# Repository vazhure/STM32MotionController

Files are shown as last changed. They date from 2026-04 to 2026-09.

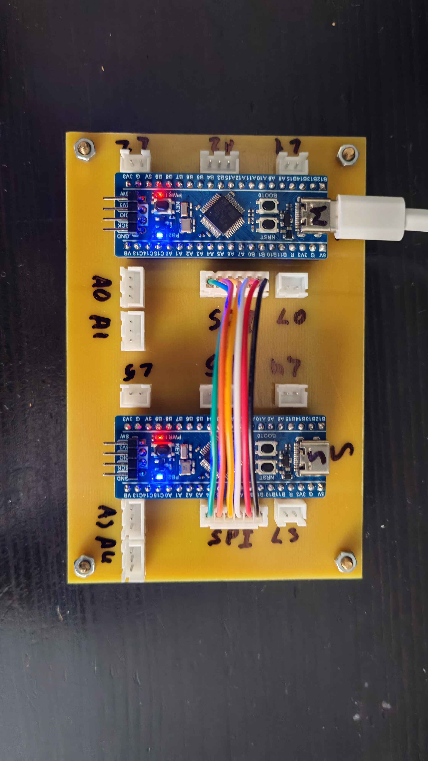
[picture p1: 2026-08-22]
STM32_F103_6DOF/photo/IMG_20260822_163101.jpg

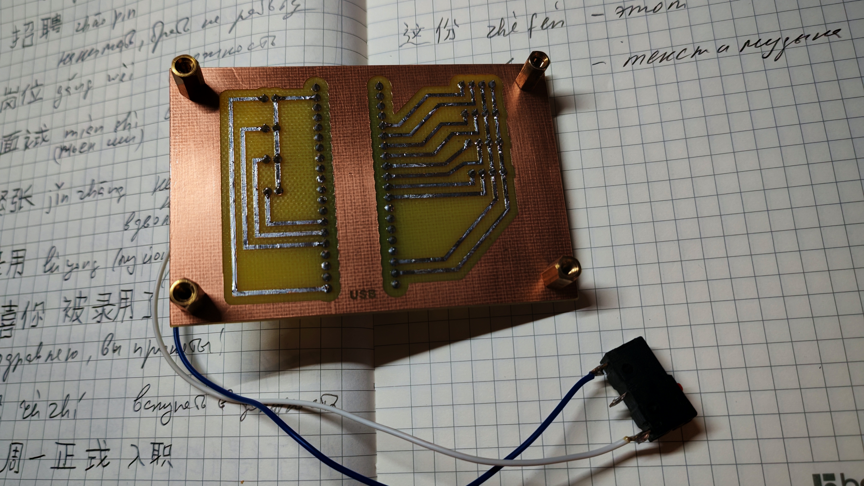
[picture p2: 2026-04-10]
STM32_F103_3DOF/img/IMG_20260410_142503.jpg

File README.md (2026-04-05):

# STM32 Motion Controller
SimHub compatible STM32 (STM32F103C8T6) based Motion Controller for Sim Racing / flight Simulators
2026-03-19 14-16-23 SettingsForm



IMG_20260319_162154_edit_288829376968099

Single STM32F103C8T6 board realization:
scheme

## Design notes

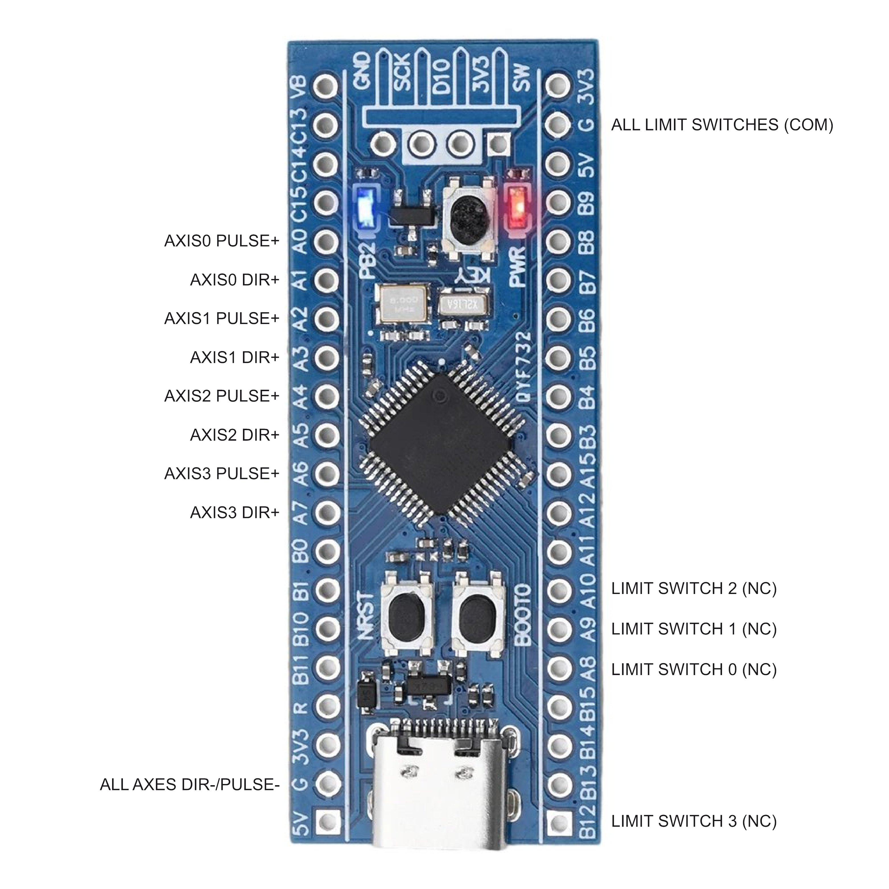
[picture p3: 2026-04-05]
STM32_F103_3DOF/img/scheme.png

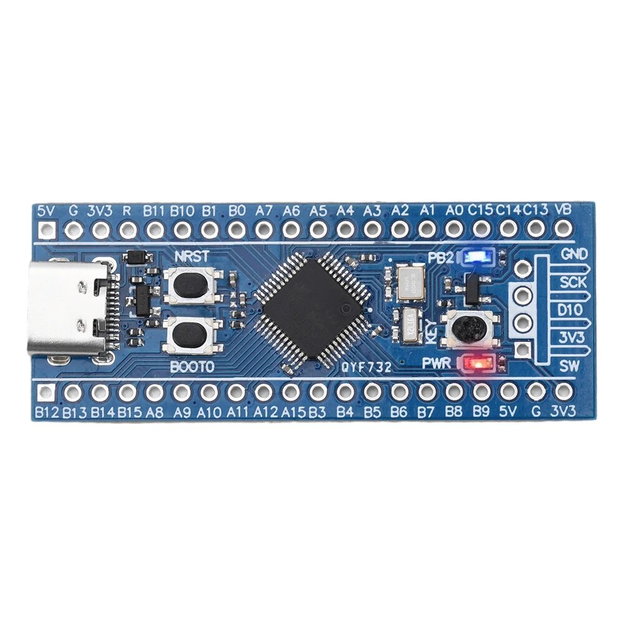
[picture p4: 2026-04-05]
STM32_F103_3DOF/img/STM32F103C8T6_TYPE_C.jpg

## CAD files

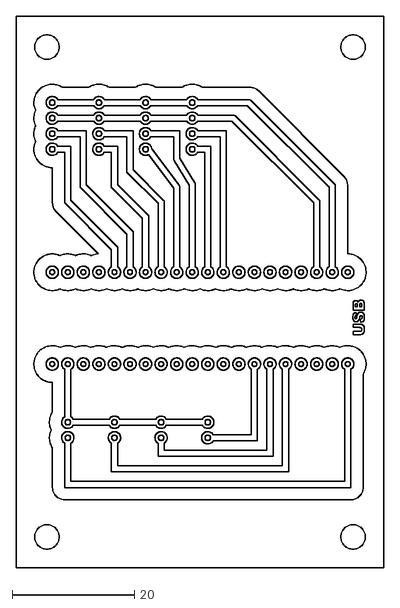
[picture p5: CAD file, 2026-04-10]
STM32_F103_3DOF/Drawings/PCB Single STM32F103_v.1.0.dxf
60.0 x 90.0

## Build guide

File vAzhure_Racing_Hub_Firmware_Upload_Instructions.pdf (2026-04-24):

vAzhure Racing Hub — Firmware Upload Instructions

## vAzhure Racing Hub

## Firmware Upload Instructions

This guide walks you through the complete process of flashing firmware onto STM32 microcontrollers used in the vAzhure Racing Hub motion controller system. You will program one Master board and up to four Slave boards, then verify that everything works with the vAzhure Racing Hub software.

Before you begin, make sure you have the following items ready:

- An ST-Link V2 (or compatible) programmer/debugger dongle
- One STM32F103C8 (or compatible) board designated as the Master
- Up to four STM32F103C8 boards designated as Slaves (Front-Left, Rear-Left, Rear-Right, Front-Right)
- USB cables to connect the ST-Link to your PC
- Jumper wires for connecting the ST-Link to each STM32 board
- The assembled PCB where the programmed boards will be installed

Warning: Always double-check the wiring connections before applying power. Connecting VCC or signal pins incorrectly may damage your STM32 board or the ST-Link programmer.

## 1. Install Required Software

You need two pieces of software installed on your computer before you can flash the firmware onto the STM32 boards. The Arduino IDE is used to compile and upload the firmware source code, while the ST-Link Utility provides the low-level USB driver that the Arduino IDE relies on for
communication with the ST-Link programmer.
Step 1.1: Download and install the Arduino IDE

Go to the official Arduino IDE releases page and download the latest version for your operating system: https://github.com/arduino/arduino-ide/releases

Run the installer and follow the on-screen prompts. Once the installation is complete, launch the Arduino IDE to verify that it opens correctly.

Step 1.2: Download and install the ST-Link USB driver

Download the ST-Link Utility from STMicroelectronics: https://www.st.com/en/development-tools/stsw-link004.html (https://www.st.com/en/development-tools/stsw-link004.html)

Install the software. This step is necessary even if you only use the Arduino IDE for uploading, because the ST-Link USB driver included in this package is required for the Arduino IDE to communicate with your ST-Link dongle.

## 2. Configure the Arduino IDE for STM32

By default, the Arduino IDE does not include support for STM32 microcontrollers. You need to add a third-party board index URL so that the IDE can download the necessary STM32 core files and board definitions.

Step 2.1: Add STM32 board manager URLs

Open the Arduino IDE and go to File > Preferences (on Windows/Linux) or Arduino IDE > Preferences (on macOS). In the Preferences window, find the field labeled "Additional boards manager URLs".

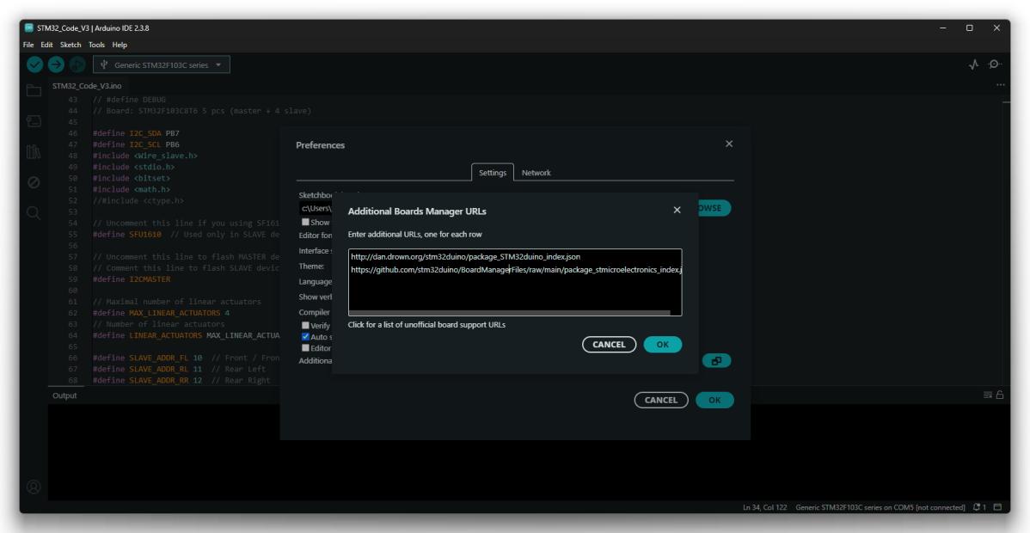
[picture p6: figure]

Append the following two URLs to that field. If there is already a URL present, separate them with a comma or place each URL on a new line:

http://dan.drown.org/stm32duino/package_STM32duino_index.json

https://github.com/stm32duino/BoardManagerFiles/raw/main/package_stmicroelectronics_index.json
Click OK to save the preferences.

Step 2.2: Install the STM32 board package

Go to Tools > Board > Boards Manager. In the search box at the top, type "STM32" and look for an entry named "STM32F1xx/GD32F1xx boards" in the list of results. Click the Install button next to it and wait for the download and installation to complete. This may take a few minutes depending on your internet speed.

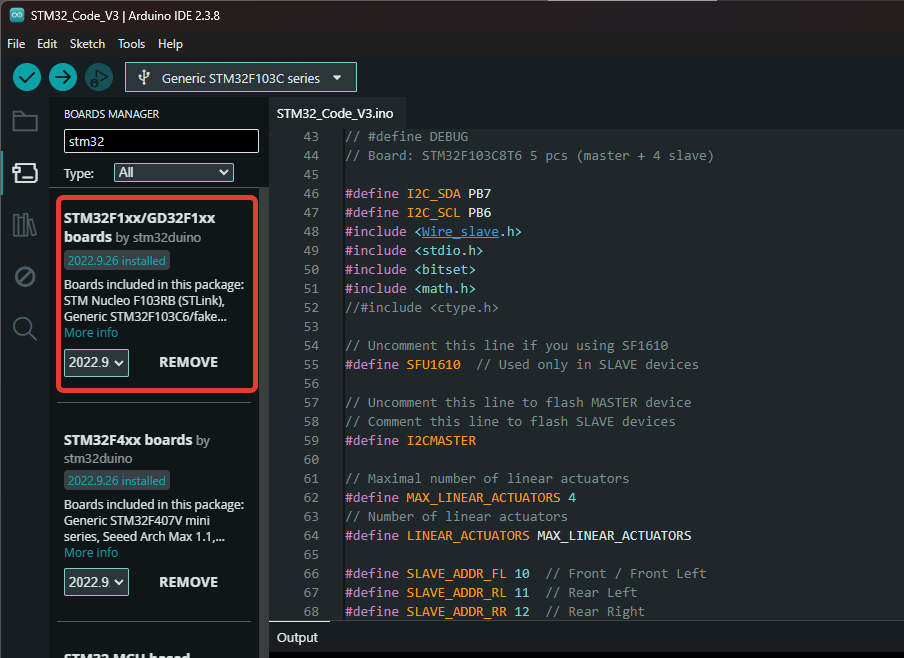
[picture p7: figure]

Step 2.3: Set the board configuration in the Tools menu

Once the STM32 board package is installed, open the Tools menu and configure the following settings exactly as shown below. These settings must match for every firmware build in this guide:

Setting | Value
Board | "Fake STM32F103C8" or "Generic STM32F103C series"
CPU Speed (MHz) | 72 MHz (Normal)
Optimize | Fast (-O1)
Upload Method | STLink

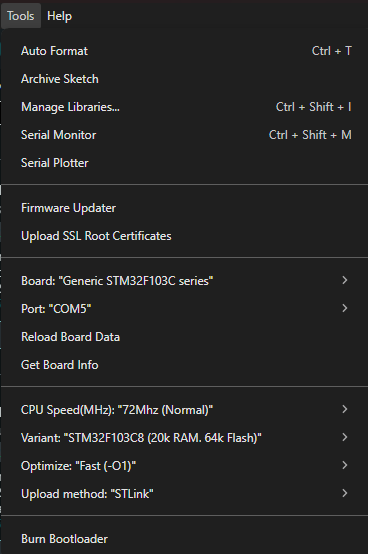
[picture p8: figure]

## 3. Wire the ST-Link to the STM32 Board

Before uploading any firmware, you need to physically connect your ST-Link programmer to the target STM32 board using jumper wires. The ST-Link communicates with the STM32 over a two-wire debug interface called SWD (Serial Wire Debug). In addition to the two data lines, you must also connect power and ground.

Use four jumper wires to make the following connections between your ST-Link dongle and the STM32 board:

ST-LINK Pin | Signal | STM32 Pin
SWCLK | → | SCK
SWDIO | → | DIO
3.3V | → | 3.3V
GND | → | GND

The following photos show how the wiring should look in practice:

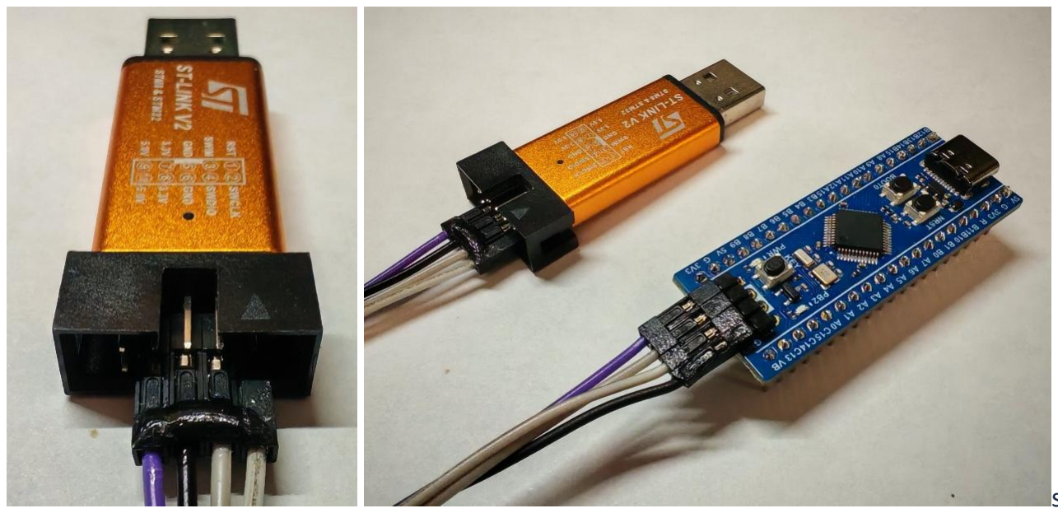
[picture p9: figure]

s

Note: Make sure the ST-Link is not connected to USB power while you are wiring the connections. Connect the USB cable only after all four wires are securely in place.

## 4. Upload the Master Firmware

The Master board is the central controller that communicates with all Slave boards over the I2C bus. It must be programmed first, because the Slave boards depend on the Master for coordination. The firmware source code is hosted on GitHub in a single sketch file.

Step 4.1: Download and open the firmware sketch

Open the following link in your browser and download the sketch file: STM32_Code_V3.ino (https://github.com/vazhure/STM32MotionController/blob/main/STM32_Code_V3/STM32_Code_V3.ino)

Open the downloaded .ino file in the Arduino IDE. The sketch will appear in the editor window.

Step 4.2: Enable the Master configuration

Near the top of the sketch file, locate the line that reads:

// #define I2CMASTER
Remove the two forward slashes at the beginning of the line so that it becomes:

#define I2CMASTER

This activates the Master mode in the firmware.

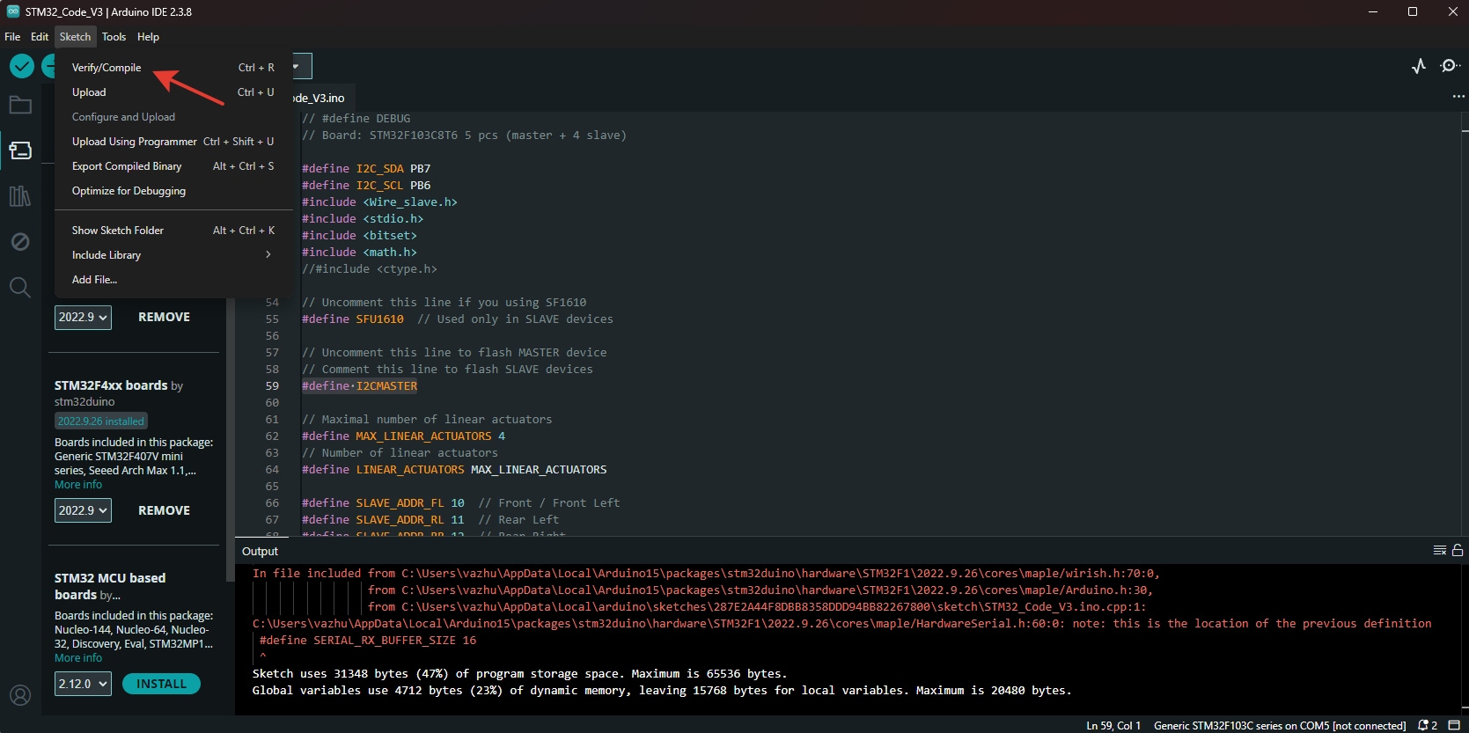
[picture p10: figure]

Step 4.3: Compile the Master firmware

Click the Verify button (the checkmark icon) in the Arduino IDE toolbar, or press Ctrl+R. Wait for the compilation to finish. If everything is configured correctly, you will see a success message in the Output panel that looks like this:

Sketch uses 31348 bytes (47%) of program storage space. Maximum is 65536 bytes.

Global variables use 4712 bytes (23%) of dynamic memory, leaving 15768 bytes for local variables. Maximum is 20480 bytes.

Note: If the compilation fails with errors, double-check that the correct board (Generic STM32F103C series) is selected in the Tools menu and that the STM32 board package was installed successfully in Step 2.2.

Step 4.4: Upload the Master firmware to the board

Connect the ST-Link dongle to your PC using a USB cable. The ST-Link driver you installed in Step 1.2 should be recognized automatically by the operating system. Then, click the Upload button (the right-arrow icon) in the Arduino IDE toolbar, or press Ctrl+U.

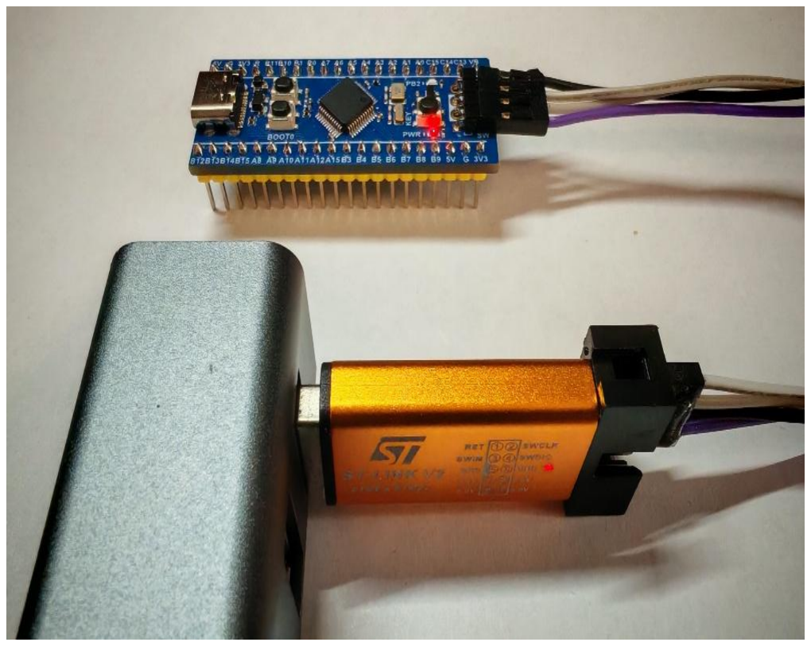
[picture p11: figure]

The Arduino IDE will compile the sketch again (if any changes were made) and then flash it onto the STM32 board through the ST-Link. Wait for the upload process to complete. A successful upload will display a message in the Output panel confirming that the firmware was written to the flash memory.

Once the upload finishes successfully, disconnect the ST-Link from the STM32 board. The Master board is now programmed and ready.

## 5. Upload the Slave Firmware

Each Slave board needs its own copy of the firmware compiled with a unique I2C address. The address is determined by which #define line is uncommented in the sketch. You will repeat the compile-and-upload cycle for each Slave board, changing only the address line each time.

Step 5.1: Switch from Master to Slave mode

In the Arduino IDE, go back to the top of the sketch file and comment out the I2CMASTER line by adding two forward slashes at the beginning:

// #define I2CMASTER
This disables Master mode and prepares the sketch for Slave mode configuration.
Step 5.2: Program the Front-Left Slave (FL)

Uncomment the line for the Front-Left slave address by removing the forward slashes:

#define SLAVE_ADDR SLAVE_ADDR_FL

Make sure all other SLAVE_ADDR lines remain commented out. Only one address line should be active at a time.

Connect the ST-Link to the Front-Left STM32 board using the same wiring diagram from Section 3. Click Verify to compile the sketch. You should see a success message similar to:

Sketch uses 34500 bytes (52%) of program storage space. Maximum is 65536 bytes.

Global variables use 4672 bytes (22%) of dynamic memory, leaving 15808 bytes for local variables. Maximum is 20480 bytes.

Click Upload to flash the firmware onto the Front-Left board. Wait for the upload to complete successfully.

Step 5.3: Program the remaining Slave boards

Repeat the process from Step 5.2 for each of the remaining Slave boards. For each board, comment out the previous SLAVE_ADDR line and uncomment the one corresponding to the current board. The complete list of Slave addresses is shown in the table below:

Slave Device | Macro to Uncomment
Front-Left (FL) | #define SLAVE_ADDR SLAVE_ADDR_FL
Rear-Left (RL) | #define SLAVE_ADDR SLAVE_ADDR_RL
Rear-Right (RR) | #define SLAVE_ADDR SLAVE_ADDR_RR
Front-Right (FR) | #define SLAVE_ADDR SLAVE_ADDR_FR

For example, to program the Rear-Left board, change the active line to:

#define SLAVE_ADDR SLAVE_ADDR_RL

Follow the same verify-and-upload cycle for each Slave: Rear-Left (RL), Rear-Right (RR), and Front-Right (FR). Connect the ST-Link to each board one at a time and upload the corresponding firmware.

Note: It is easy to forget to change the address line between uploads. Always verify that
only the correct SLAVE_ADDR line is uncommented before clicking Upload. Uploading the wrong address to a board will cause I2C communication conflicts later.

## 6. Install the Programmed Boards on the PCB

Once all boards have been successfully programmed, carefully install them onto the motion controller PCB. Pay close attention to the physical orientation and the slot assignments for each board. The Master board must be placed in its designated position, and each Slave board must occupy the correct slot matching the address that was programmed into it.

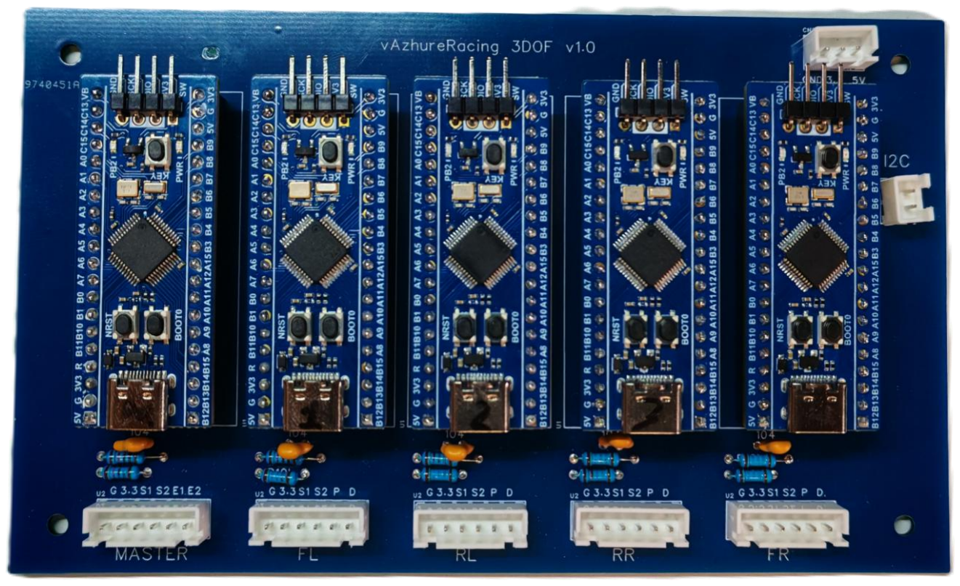
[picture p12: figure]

Verify that the boards are seated properly in their sockets and that no pins are bent or misaligned. A loose connection can cause intermittent failures that are difficult to diagnose later.

## 7. Install and Run the vAzhure Racing Hub Software

With the hardware fully assembled, the final step is to install the vAzhure Racing Hub application on your PC. This software communicates with the Master STM32 board over USB and provides the user interface for configuring and controlling the motion platform.

Step 7.1: Download and install the software

Go to the releases page on GitHub and download the latest version of the vAzhure Racing Hub: https://github.com/vazhure/vAzhureRacingHub/releases

Extract the archive and run the installer (or launch the executable directly if it is a portable version). Follow the installation prompts to complete the setup.

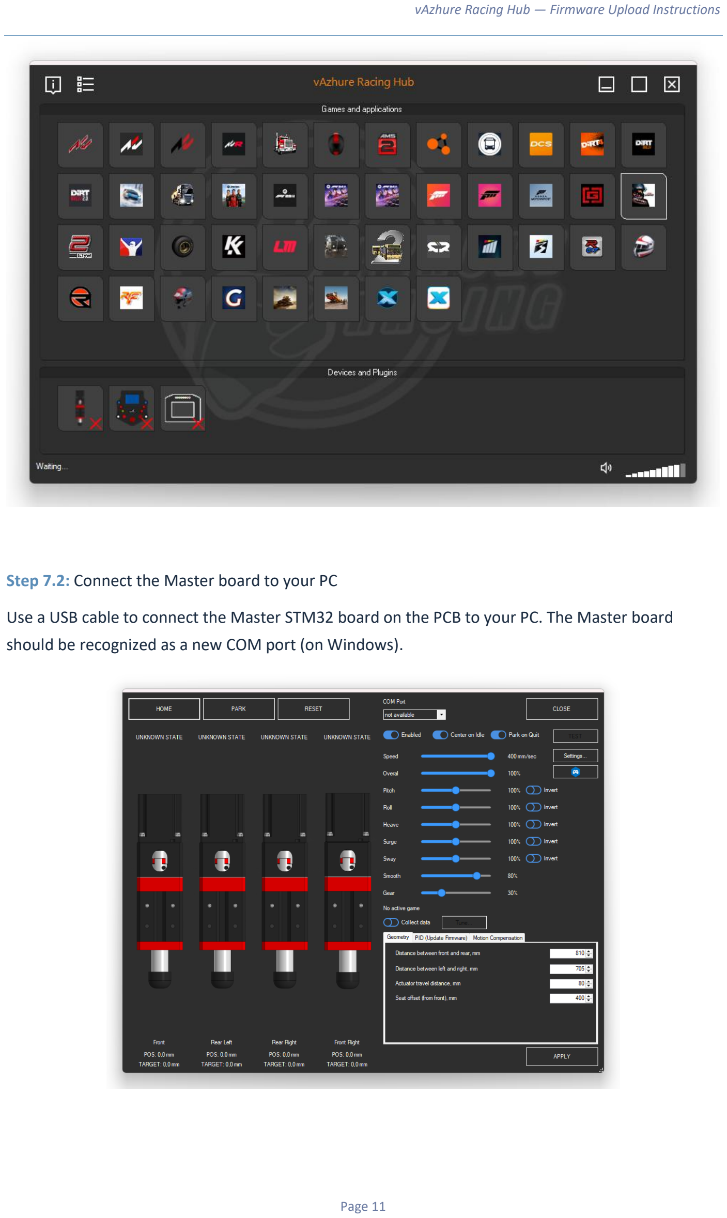
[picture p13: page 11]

Step 7.2: Connect the Master board to your PC

Use a USB cable to connect the Master STM32 board on the PCB to your PC. The Master board should be recognized as a new COM port (on Windows).

Step 7.3: Detect the device in the software

Launch the vAzhure Racing Hub application. Click the device detection icon in the toolbar to scan for connected hardware.

When the software detects the Master board, a dialog will appear asking whether you want to register the new device. Click "Yes" to confirm.

Step 7.4: Verify the setup

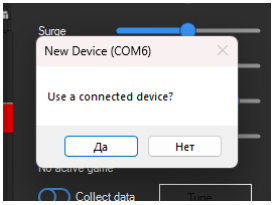
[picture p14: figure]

If the PCB is assembled correctly and all firmware was flashed properly, the software should display the full system status with all Slave boards reporting in. You should see indicators for each axis (Front-Left, Front-Right, Rear-Left, Rear-Right) showing that they are online and responding to commands from the Master.

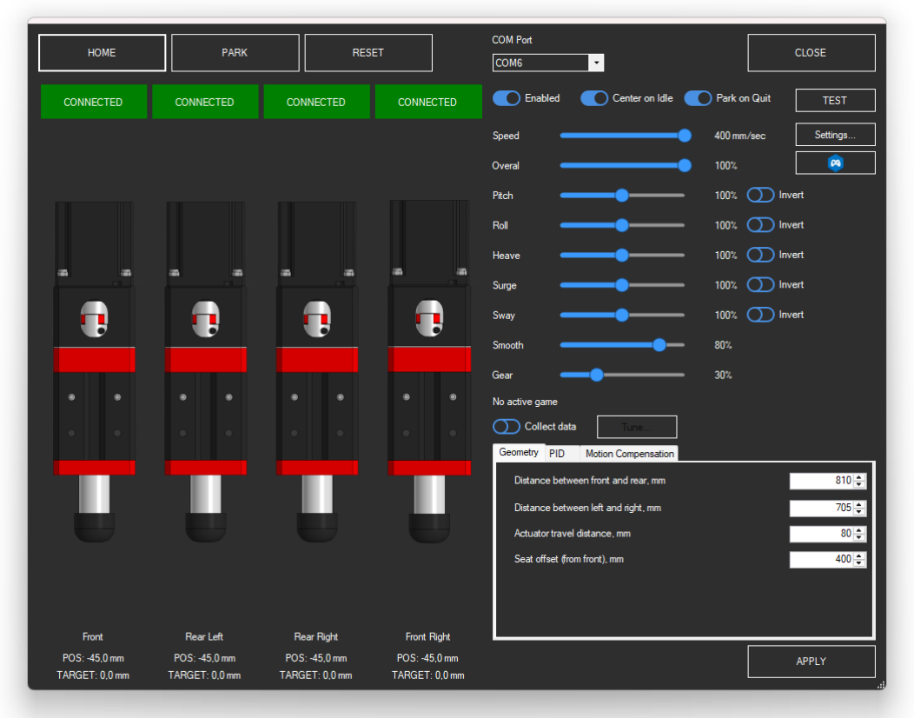
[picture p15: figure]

If any boards are not showing up, go back and verify the following:

- The correct firmware was uploaded to each board (check the SLAVE_ADDR lines)
- All boards are properly seated in their PCB sockets
- The USB cable and connection are working (try a different cable or port)
- The ST-Link USB driver is installed (required for COM port detection)

Congratulations! Your vAzhure Racing Hub motion controller is now fully set up and ready to use.

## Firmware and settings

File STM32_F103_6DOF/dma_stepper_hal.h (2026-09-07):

// 3DOF by Andrey Zhuravlev
// v.azhure@gmail.com
// Discord: https://discord.gg/ynHCkrsmMA
// ============================================================================
// CHANGELOG:
// 2026-09-07: Acceleration fix. CMD_ENABLE fix (preserve PARKED state)
// 2026-08-19: Added COMMAND enum to make it visible in both .cpp and .ino files.
// 2026-08-18: Merged 6-axis SPI Master/Slave support with advanced limit switch config.
// ============================================================================
#ifndef DMA_STEPPER_HAL_H
#define DMA_STEPPER_HAL_H
#include <Arduino.h>

// =============================================================================
// 🛠️ USER CONFIGURATION (Modify only these values)
// =============================================================================
#define MM_PER_REV 8.0f
#define STEPS_PER_REV 1600
#define MAX_REVOLUTIONS 20.0f

#define HOME_DIRECTION -1
#define END_CLEARANCE_MM 3.0f

#define LIMIT_TYPE_NC 0
#define LIMIT_TYPE_NO 1
#define LIMIT_PULL_UP 0
#define LIMIT_PULL_DOWN 1
#define LIMIT_PULL_AUTO 2

#ifndef LIMIT_SWITCH_TYPE
#define LIMIT_SWITCH_TYPE LIMIT_TYPE_NO
#endif
#ifndef LIMIT_PULL_MODE
#define LIMIT_PULL_MODE LIMIT_PULL_AUTO
#endif

#if (LIMIT_PULL_MODE == LIMIT_PULL_AUTO)
#if (LIMIT_SWITCH_TYPE == LIMIT_TYPE_NC)
#define _RESOLVED_PULL LIMIT_PULL_UP
#else
#define _RESOLVED_PULL LIMIT_PULL_DOWN
#endif
#else
#define _RESOLVED_PULL LIMIT_PULL_MODE
#endif

#if (LIMIT_SWITCH_TYPE == LIMIT_TYPE_NC)
#if (_RESOLVED_PULL == LIMIT_PULL_UP)
#define LIMIT_ACTIVE_HIGH 1
#else
#define LIMIT_ACTIVE_HIGH 0
#endif
#else
#if (_RESOLVED_PULL == LIMIT_PULL_UP)
#define LIMIT_ACTIVE_HIGH 0
#else
#define LIMIT_ACTIVE_HIGH 1
#endif
#endif

#define END_CLEARANCE_STEPS ((int32_t)(END_CLEARANCE_MM * (float)STEPS_PER_REV / (float)MM_PER_REV))

// =============================================================================
// ENABLE SWITCH  CONFIGURATION
// =============================================================================
#define ENABLE_PIN PB11 // PB12, PB6, PB7, PB8, PB9  // NC button: LOW = running, HIGH = paused

// =============================================================================
// MULTI-CONTROLLER CONFIGURATION
// =============================================================================
#define AXES_PER_BOARD 3
#define AXES_TOTAL 6

#define CONTROLLER_MODE_MASTER 0
#define CONTROLLER_MODE_SLAVE 1

#ifndef CONTROLLER_MODE
#define CONTROLLER_MODE CONTROLLER_MODE_SLAVE
#endif

#if (CONTROLLER_MODE == CONTROLLER_MODE_SLAVE)
#define LOGICAL_AXIS_OFFSET AXES_PER_BOARD
#else
#define LOGICAL_AXIS_OFFSET 0
#endif

#define SPI_SCK_PIN PA5
#define SPI_MISO_PIN PA6
#define SPI_MOSI_PIN PA7
#define SPI_NSS_PIN PA4
#define SYNC_PIN PB0
#define ALARM_PIN PB1

#define SPI_HEADER_MAGIC 0xAA

// 2026-08-19 FIX: Double underscore for packed attribute
typedef struct __attribute__((packed)) {
  uint8_t header;
  uint8_t frameId;
  uint8_t command;
  uint8_t flags;
  int32_t cmdData[3];
  int32_t positions[3];
  int32_t targets[3];
  uint8_t modes[3];
  uint8_t slaveStatus;
} SPI_FRAME;

#define SPI_FLAG_SYNC 0x01
#define SPI_FLAG_ALARM 0x02

// =============================================================================
// PROTOCOL COMMANDS (Moved here so .cpp and .ino can both see them)
// =============================================================================
enum COMMAND : uint8_t {
  CMD_HOME = 0,
  CMD_MOVE = 1,
  CMD_SET_SPEED = 2,
  CMD_DISABLE = 3,
  CMD_ENABLE = 4,
  CMD_GET_STATE = 5,
  CMD_CLEAR_ALARM = 6,
  CMD_PARK = 7,
  SET_ALARM = 8,
  CMD_SET_LOW_SPEED = 9,
  CMD_SET_ACCEL = 10,
  CMD_MOVE_SH = 11,
  CMD_SET_PID_KP = 0x0C,
  CMD_SET_PID_KI = 0x0D,
  CMD_SET_PID_KD = 0x0E,
  CMD_SET_PID_KS = 0x0F,
  CMD_SET_PID_ENABLE = 0x10,
  CMD_SET_PID_BLEND = 0x11,
  CMD_GET_PID_STATE = 0x12,
  CMD_STORE_PID = 0x13,
  CMD_RESTORE_PID = 0x14,
};

// =============================================================================
// UNIT CONVERSION MACROS
// =============================================================================
#define MMPERSECTOFREQHZ(mmpers) ((uint32_t)((float)(mmpers) * (float)STEPS_PER_REV / (float)MM_PER_REV))
#define FREQHZTOMMPERSEC(freqhz) ((float)(freqhz) * (float)MM_PER_REV / (float)STEPS_PER_REV)
#define MMPERSECTOFREQHZ_SAFE(mmpers) constrain(MMPERSECTOFREQHZ(mmpers), MIN_FREQUENCY_HZ, MAX_FREQUENCY_HZ)

#define MAX_FREQUENCY_HZ 200000
#define SAFE_FREQUENCY_HZ 100000
#define DEFAULT_FREQUENCY_HZ SAFE_FREQUENCY_HZ
#define MIN_FREQUENCY_HZ 50

#define HOMING_FREQUENCY_HZ MMPERSECTOFREQHZ_SAFE(15)
#define PARKING_FREQUENCY_HZ MMPERSECTOFREQHZ_SAFE(15)
#define HOMING_RETRACT_DISTANCE_MM 3.0f
#define HOMING_RETRACT_DURATION_MS ((uint32_t)((HOMING_RETRACT_DISTANCE_MM * (float)STEPS_PER_REV * 1000.0f) / ((float)HOMING_FREQUENCY_HZ * MM_PER_REV)))
#define HOMING_SEEK_TIMEOUT_MS 30000
#define HOMING_CENTER_TIMEOUT_MS 30000
#define MAX_ACCEL 80000
#define HOMING_TRAVEL_LIMIT_MULT 1.5f
#define HOMING_OVERFLOW_LIMIT_MULT 1.4f
#define POSITION_TOLERANCE 50

#define POSITION_DEADZONE 4 //2
#define ACCEL_RAMP_DISTANCE 800 //50

// S-curve softening: limit how fast frequency can change per call
// This prevents "frequency shock" when target changes abruptly
#define MAX_FREQ_DELTA_PER_CALL 2000 

#define DIRECTION_CHANGE_DELAY_US 10
#define HOMING_CENTER_TOLERANCE 100
#define HOMING_RETRACT_SETTLE_MS 50

// =============================================================================
// SYSTEM CONSTANTS
// =============================================================================
#define MM_PER_STEP (MM_PER_REV / STEPS_PER_REV)
#define MAX_SPEED_MM_SEC (int)(MAX_FREQUENCY_HZ * MM_PER_STEP)
#define SAFE_SPEED_MM_SEC (int)(SAFE_FREQUENCY_HZ * MM_PER_STEP)
#define DEFAULT_SPEED_MM_SEC (int)(DEFAULT_FREQUENCY_HZ * MM_PER_STEP)
#define NUM_AXES AXES_PER_BOARD
#define PENDING_TARGET_NONE INT32_MIN

// =============================================================================
// DATA STRUCTURES
// =============================================================================
typedef struct {
  uint8_t stepPin;
  uint8_t dirPin;
  uint8_t limitPin;
} AxisConfig;

typedef struct {
  volatile int32_t currentPosition;
  volatile int32_t targetPosition;
  volatile int32_t minPos;
  volatile int32_t maxPos;
  volatile uint32_t frequency;
  volatile bool direction;
  volatile bool stepping;
  volatile bool homed;
  volatile uint8_t mode;
  uint32_t maxFreqHz;
  uint32_t maxSpeedMM;
  float limitedFreq;
  uint32_t accelLastTime;
  uint32_t pidLastTime;
  uint32_t maxAccel;
  float Kp, Ki, Kd, Ks;
  float integral;
  float prevError;
  float derivativeFilter;
  float pidMinFreq;
  float pidMaxFreq;
  bool pidEnabled;
  float pidBlend;
  int32_t pendingTarget;
} AxisState;

enum AxisMode {
  MODE_UNKNOWN = 0,
  MODE_CONNECTED = 1,
  MODE_DISABLED = 2,
  MODE_HOMING = 3,
  MODE_PARKING = 4,
  MODE_READY = 5,
  MODE_ALARM = 6,
  MODE_PARKED = 7,
  MODE_UNPARKING = 8
};

enum HomingSubState {
  H_IDLE = 0,
  H_SEEKING,
  H_RETRACT,
  H_RETRACT_SETTLE,
  H_MOVING_CENTER,
  H_DONE
};

// =============================================================================
// API FUNCTIONS
// =============================================================================
void DMAStepper_Init(void);
void DMAStepper_InitAxis(uint8_t axisIdx, uint8_t stepPin, uint8_t dirPin, uint8_t limitPin);
void DMAStepper_SetFrequency(uint8_t axisIdx, uint32_t freqHz);
void DMAStepper_StartAxis(uint8_t axisIdx, bool forward);
void DMAStepper_StopAxis(uint8_t axisIdx);
void DMAStepper_StopAll(void);
void DMAStepper_SetTarget(uint8_t axisIdx, int32_t target);
int32_t DMAStepper_GetPosition(uint8_t axisIdx);
void DMAStepper_SetPosition(uint8_t axisIdx, int32_t pos);
AxisState* DMAStepper_GetAxis(uint8_t axisIdx);
void DMAStepper_SetMaxSpeed(uint8_t axisIdx, uint32_t speedMM);
void DMAStepper_SetPID(uint8_t axisIdx, float Kp, float Ki, float Kd, float Ks);
void DMAStepper_SetPIDEnable(uint8_t axisIdx, bool enable);
void DMAStepper_SetPIDBlend(uint8_t axisIdx, float blend);
bool DMAStepper_CheckLimit(uint8_t axisIdx);
void DMAStepper_ClearAlarm(void);
void DMAStepper_Process(void);
void DMAStepper_StartHoming(uint8_t axisIdx);

void SPI_Controller_Init(void);
void SPI_Controller_Process(void);
void SPI_PingSlave(void); 
bool SPI_Controller_SendCommand(uint8_t cmd, int32_t* data, bool sync);
bool SPI_Controller_IsSlaveReady(void);
void SPI_Controller_TriggerAlarm(void);
SPI_FRAME* SPI_Controller_GetLastFrame(void);

#endif

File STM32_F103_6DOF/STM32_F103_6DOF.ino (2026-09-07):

/*
🛠️ COMPILATION & SETUP INSTRUCTIONS
Board: "Generic STM32F1 series" → "Blue Pill F103C8"
Upload method: "STLink", CPU Speed: "72 MHz (Normal)"

6-AXIS SYSTEM WIRING (identical on both boards):
AXIS0: PA0 (STEP), PA1 (DIR), PB10 (LIMIT)
AXIS1: PA2 (STEP), PA3 (DIR), PA8  (LIMIT)
AXIS2: PB3 (STEP), PB4 (DIR), PB5  (LIMIT)

SPI interconnect (Master ↔ Slave):
PA5 (SCK), PA6 (MISO), PA7 (MOSI), PA4 (NSS)
PB0 (SYNC), PB1 (ALARM), GND (common ground required!)

MASTER board: connect USB to PC/SimHub
SLAVE board:  powered separately, no USB needed

IMPORTANT: 
To compile for Master, ensure dma_stepper_hal.h has: #define CONTROLLER_MODE CONTROLLER_MODE_MASTER
To compile for Slave, ensure dma_stepper_hal.h has:  #define CONTROLLER_MODE CONTROLLER_MODE_SLAVE
*/

// 2026-09-07: Acceleration fix. CMD_ENABLE fix (preserve PARKED state)
// 2026-08-23 CRITICAL FIX: Disable JTAG to free PB3, PB4, PA15 for GPIO use.
// 2026-08-19: Moved COMMAND enum to dma_stepper_hal.h to fix compilation scope errors.
// 3DOF by Andrey Zhuravlev
// v.azhure@gmail.com
// Discord: https://discord.gg/ynHCkrsmMA

#include "dma_stepper_hal.h"
#include <EEPROM.h>
#include <string.h>

#define SERIAL_BAUD_RATE 115200
#define PID_KP_SCALE 10.0f
#define PID_KI_SCALE 10.0f
#define PID_KD_SCALE 100.0f
#define PID_KS_SCALE 100.0f
#define SH_DATA_MAX_VALUE 65535

#define AXIS0_STEP PA0
#define AXIS0_DIR PA1
#define AXIS0_LIMIT PB10
#define AXIS1_STEP PA2
#define AXIS1_DIR PA3
#define AXIS1_LIMIT PA8
#define AXIS2_STEP PB3
#define AXIS2_DIR PB4
#define AXIS2_LIMIT PB5
#define LED_PIN PB2

#define CMD_ID 0
#define STATE_SIZE 20
#define PID_STATE_SIZE 20

// enum COMMAND удален отсюда, так как теперь он объявлен в dma_stepper_hal.h

struct __attribute__((packed)) PCCMD {
  uint8_t header;
  uint8_t len;
  COMMAND cmd;
  uint8_t reserved;
  int32_t data[AXES_TOTAL];
};

struct __attribute__((packed)) PCCMD_SH {
  uint8_t header = 0;
  uint8_t len;
  COMMAND cmd;
  uint8_t reserved;
  uint16_t data[AXES_TOTAL];
  uint16_t data2[AXES_TOTAL];
};

struct __attribute__((packed)) STATE {
  uint8_t mode;
  uint8_t flags;
  uint16_t speedMMperSEC;
  int32_t currentpos;
  int32_t targetpos;
  int32_t min;
  int32_t max;
};

struct __attribute__((packed)) PID_STATE {
  uint8_t version;
  uint8_t flags;
  uint16_t blend;
  float Kp, Ki, Kd, Ks;
};

enum PID_FLAGS : uint8_t {
  PID_NONE = 0,
  PID_ENABLED = 1,
  PID_MASTER_SYNC = 1 << 1,
  PID_DIAG_ENABLED = 1 << 2
};

PCCMD pccmd;
PCCMD_SH& pccmd_sh = (PCCMD_SH&)pccmd;
const int RAW_DATA_LEN = sizeof(PCCMD);

volatile bool dataReceived = false;
uint8_t rxBuffer[RAW_DATA_LEN * 2];
int rxOffset = 0;

PID_STATE pidGlobal = {
  .version = 1, .flags = PID_FLAGS::PID_ENABLED, .blend = 100, .Kp = 15.0f, .Ki = 0.0f, .Kd = 0.02f, .Ks = 0.30f
};
const int PID_STATE_LEN = sizeof(PID_STATE);
#define PID_EEPROM_MAGIC 0x5A
#define PID_EEPROM_ADDR 0

void savePidToEEPROM() {
  EEPROM.update(PID_EEPROM_ADDR, PID_EEPROM_MAGIC);
  uint8_t* p = (uint8_t*)&pidGlobal;
  for (int i = 0; i < PID_STATE_LEN; i++) EEPROM.update(PID_EEPROM_ADDR + 1 + i, p[i]);
}

bool loadPidFromEEPROM() {
  if (EEPROM.read(PID_EEPROM_ADDR) != PID_EEPROM_MAGIC) return false;
  uint8_t* p = (uint8_t*)&pidGlobal;
  for (int i = 0; i < PID_STATE_LEN; i++) p[i] = EEPROM.read(PID_EEPROM_ADDR + 1 + i);
  return true;
}

void sendAllStates() {
  for (int logicalAxis = 0; logicalAxis < AXES_TOTAL; logicalAxis++) {
    STATE s;
    memset(&s, 0, sizeof(s));

#if (CONTROLLER_MODE == CONTROLLER_MODE_MASTER)
    if (logicalAxis < AXES_PER_BOARD) {
      AxisState* ax = DMAStepper_GetAxis(logicalAxis);
      if (!ax) continue;
      s.mode = ax->mode;
      s.flags = ax->homed ? 0x02 : 0;
      s.speedMMperSEC = (uint16_t)ax->maxSpeedMM;
      s.currentpos = ax->currentPosition;
      s.targetpos = ax->targetPosition;
      s.min = ax->minPos;
      s.max = ax->maxPos;
    } else {
      // Remote axes 3-5 (from Slave via SPI)
      int slaveIdx = logicalAxis - AXES_PER_BOARD;
      SPI_FRAME* frame = SPI_Controller_GetLastFrame();

      // 2026-08-19 CRITICAL FIX: NEVER skip axes — always send something.
      // If Slave is offline/in alarm, send explicit "no data" state with flag 0x08.
      if (!frame) {
        s.mode = 0;      // MODE_UNKNOWN
        s.flags = 0x08;  // Special flag: "no data from slave"
        s.speedMMperSEC = 0;
        s.currentpos = 0;
        s.targetpos = 0;
        s.min = 0;
        s.max = 0;
      } else {
        s.mode = frame->modes[slaveIdx];
        s.flags = (frame->slaveStatus & (1 << slaveIdx)) ? 0x02 : 0;
        if (frame->slaveStatus & 0x08) s.flags |= 0x04;  // Alarm flag
        s.speedMMperSEC = 0;
        s.currentpos = frame->positions[slaveIdx];
        s.targetpos = frame->targets[slaveIdx];
        AxisState* ax = DMAStepper_GetAxis(slaveIdx);
        s.min = ax->minPos;
        s.max = ax->maxPos;
      }
    }
#else
    if (logicalAxis < LOGICAL_AXIS_OFFSET || logicalAxis >= LOGICAL_AXIS_OFFSET + AXES_PER_BOARD) continue;
    int localIdx = logicalAxis - LOGICAL_AXIS_OFFSET;
    AxisState* ax = DMAStepper_GetAxis(localIdx);
    if (!ax) continue;
    s.mode = ax->mode;
    s.flags = ax->homed ? 0x02 : 0;
    s.speedMMperSEC = (uint16_t)ax->maxSpeedMM;
    s.currentpos = ax->currentPosition;
    s.targetpos = ax->targetPosition;
    s.min = ax->minPos;
    s.max = ax->maxPos;
#endif

    Serial.write(10 + logicalAxis);
    Serial.write(STATE_SIZE);
    Serial.write((uint8_t*)&s, STATE_SIZE);
  }
}

void sendPIDState() {
  Serial.write(255);
  Serial.write(PID_STATE_SIZE);
  Serial.write((uint8_t*)&pidGlobal, PID_STATE_SIZE);
}

void processCommand() {
  switch (pccmd.cmd) {
    case CMD_MOVE:
      {
#if (CONTROLLER_MODE == CONTROLLER_MODE_MASTER)
        for (int i = 0; i < AXES_PER_BOARD; i++) {
          AxisState* ax = DMAStepper_GetAxis(i);
          if (!ax || !ax->homed) continue;
          if (ax->mode == MODE_READY) DMAStepper_SetTarget(i, pccmd.data[i]);
          else if (ax->mode == MODE_PARKED || ax->mode == MODE_UNPARKING) {
            ax->pendingTarget = pccmd.data[i];
            if (ax->mode == MODE_PARKED) ax->mode = MODE_UNPARKING;
          }
        }
        int32_t slaveData[3] = { pccmd.data[3], pccmd.data[4], pccmd.data[5] };
        SPI_Controller_SendCommand(CMD_MOVE, slaveData, false);
#endif
        break;
      }
    case CMD_MOVE_SH:
      {
#if (CONTROLLER_MODE == CONTROLLER_MODE_MASTER)
        for (int i = 0; i < AXES_PER_BOARD; i++) {
          uint16_t val = pccmd_sh.data[i];
          val = (val >> 8) | (val << 8);
          AxisState* ax = DMAStepper_GetAxis(i);
          if (!ax || !ax->homed) continue;
          int32_t target = map(val, 0, SH_DATA_MAX_VALUE, ax->minPos, ax->maxPos);
          if (ax->mode == MODE_READY) DMAStepper_SetTarget(i, target);
          else if (ax->mode == MODE_PARKED || ax->mode == MODE_UNPARKING) {
            ax->pendingTarget = target;
            if (ax->mode == MODE_PARKED) ax->mode = MODE_UNPARKING;
          }
        }
        int32_t slaveData[AXES_PER_BOARD];
        for (int i = 0; i < AXES_PER_BOARD; i++) {
          uint16_t val = pccmd_sh.data[AXES_PER_BOARD + i];
          val = (val >> 8) | (val << 8);
          AxisState* refAx = DMAStepper_GetAxis(0);
          if (refAx) slaveData[i] = map(val, 0, SH_DATA_MAX_VALUE, refAx->minPos, refAx->maxPos);
        }
        SPI_Controller_SendCommand(CMD_MOVE, slaveData, false);
#endif
        break;
      }
    case CMD_SET_SPEED:
      {
#if (CONTROLLER_MODE == CONTROLLER_MODE_MASTER)
        for (int i = 0; i < AXES_PER_BOARD; i++) DMAStepper_SetMaxSpeed(i, (uint32_t)pccmd.data[0]);
        int32_t spdData[3] = { pccmd.data[0], 0, 0 };
        SPI_Controller_SendCommand(CMD_SET_SPEED, spdData, false);
#endif
        break;
      }
    case CMD_SET_ACCEL:
      {
#if (CONTROLLER_MODE == CONTROLLER_MODE_MASTER)
        for (int i = 0; i < AXES_PER_BOARD; i++) {
          AxisState* ax = DMAStepper_GetAxis(i);
          if (ax) ax->maxAccel = pccmd.data[0];
        }
        int32_t accData[3] = { pccmd.data[0], 0, 0 };
        SPI_Controller_SendCommand(CMD_SET_ACCEL, accData, false);
#endif
        break;
      }
    case CMD_ENABLE:
      {
#if (CONTROLLER_MODE == CONTROLLER_MODE_MASTER)
        for (int i = 0; i < AXES_PER_BOARD; i++) {
          AxisState* ax = DMAStepper_GetAxis(i);
          if (!ax) continue;

          // CRITICAL FIX: Only transition to READY from safe states.
          // Do NOT override PARKED/PARKING/UNPARKING — the unpark logic
          // must complete its smooth centering sequence first.
          // Do NOT override HOMING — let it finish.
          // Do NOT override ALARM — user must clear it explicitly.
          if (ax->mode == MODE_CONNECTED || ax->mode == MODE_DISABLED || ax->mode == MODE_UNKNOWN) {
            ax->mode = ax->homed ? MODE_READY : MODE_CONNECTED;
          }
          // PARKED stays PARKED → CMD_MOVE will trigger UNPARKING naturally
          // HOMING stays HOMING → will transition to READY when done
          // ALARM stays ALARM → user must press CLEAR_ALARM
        }
        SPI_Controller_SendCommand(CMD_ENABLE, nullptr, false);
#endif
        break;
      }
    case CMD_DISABLE:
      {
#if (CONTROLLER_MODE == CONTROLLER_MODE_MASTER)
        DMAStepper_StopAll();
        for (int i = 0; i < AXES_PER_BOARD; i++) {
          AxisState* ax = DMAStepper_GetAxis(i);
          if (ax) ax->mode = MODE_DISABLED;
        }
        SPI_Controller_SendCommand(CMD_DISABLE, nullptr, false);
#endif
        break;
      }
    case CMD_CLEAR_ALARM:
      {
#if (CONTROLLER_MODE == CONTROLLER_MODE_MASTER)
        DMAStepper_ClearAlarm();
        SPI_Controller_SendCommand(CMD_CLEAR_ALARM, nullptr, false);
#endif
        break;
      }
    case CMD_HOME:
      {
#if (CONTROLLER_MODE == CONTROLLER_MODE_MASTER)
        for (int i = 0; i < AXES_PER_BOARD; i++) {
          AxisState* ax = DMAStepper_GetAxis(i);
          if (!ax) continue;
          // 2026-08-21 FIX: Игнорируем команду, если гоминг уже идет
          if (ax->mode == MODE_HOMING) continue;
          if (ax->homed && (ax->mode == MODE_READY || ax->mode == MODE_PARKED)) continue;
          DMAStepper_StartHoming(i);
        }
        SPI_Controller_SendCommand(CMD_HOME, nullptr, false);
#endif
        break;
      }
    case CMD_PARK:
      {
#if (CONTROLLER_MODE == CONTROLLER_MODE_MASTER)
        for (int i = 0; i < AXES_PER_BOARD; i++) {
          AxisState* ax = DMAStepper_GetAxis(i);
          if (ax && ax->homed) ax->mode = MODE_PARKING;
        }
        SPI_Controller_SendCommand(CMD_PARK, nullptr, false);
#endif
        break;
      }
    case SET_ALARM:
      {
#if (CONTROLLER_MODE == CONTROLLER_MODE_MASTER)
        DMAStepper_StopAll();
        for (int i = 0; i < AXES_PER_BOARD; i++) {
          AxisState* ax = DMAStepper_GetAxis(i);
          if (ax) {
            ax->mode = MODE_ALARM;
            ax->homed = false;
          }
        }
        SPI_Controller_SendCommand(SET_ALARM, nullptr, false);
#endif
        break;
      }
    case CMD_GET_STATE:
      {
#if (CONTROLLER_MODE == CONTROLLER_MODE_MASTER)
        SPI_Controller_SendCommand(CMD_GET_STATE, nullptr, false);
#endif
        sendAllStates();
        break;
      }
    case CMD_SET_PID_KP:
      {
        pidGlobal.Kp = constrain((float)pccmd.data[0] / PID_KP_SCALE, 0.0f, 200.0f);
        for (int i = 0; i < AXES_PER_BOARD; i++) DMAStepper_SetPID(i, pidGlobal.Kp, pidGlobal.Ki, pidGlobal.Kd, pidGlobal.Ks);
        break;
      }
    case CMD_SET_PID_KI:
      {
        pidGlobal.Ki = constrain((float)pccmd.data[0] / PID_KI_SCALE, 0.0f, 50.0f);
        for (int i = 0; i < AXES_PER_BOARD; i++) DMAStepper_SetPID(i, pidGlobal.Kp, pidGlobal.Ki, pidGlobal.Kd, pidGlobal.Ks);
        break;
      }
    case CMD_SET_PID_KD:
      {
        pidGlobal.Kd = constrain((float)pccmd.data[0] / PID_KD_SCALE, 0.0f, 50.0f);
        for (int i = 0; i < AXES_PER_BOARD; i++) DMAStepper_SetPID(i, pidGlobal.Kp, pidGlobal.Ki, pidGlobal.Kd, pidGlobal.Ks);
        break;
      }
    case CMD_SET_PID_KS:
      {
        pidGlobal.Ks = constrain((float)pccmd.data[0] / PID_KS_SCALE, 0.0f, 1.0f);
        for (int i = 0; i < AXES_PER_BOARD; i++) DMAStepper_SetPID(i, pidGlobal.Kp, pidGlobal.Ki, pidGlobal.Kd, pidGlobal.Ks);
        break;
      }
    case CMD_SET_PID_ENABLE:
      {
        for (int i = 0; i < AXES_PER_BOARD; i++) DMAStepper_SetPIDEnable(i, pccmd.data[0] != 0);
        if (pccmd.data[0]) pidGlobal.flags |= PID_FLAGS::PID_ENABLED;
        else pidGlobal.flags &= ~PID_FLAGS::PID_ENABLED;
        break;
      }
    case CMD_SET_PID_BLEND:
      {
        pidGlobal.blend = constrain((uint16_t)pccmd.data[0], 0, 100);
        for (int i = 0; i < AXES_PER_BOARD; i++) DMAStepper_SetPIDBlend(i, (float)pidGlobal.blend / 100.0f);
        break;
      }
    case CMD_GET_PID_STATE:
      {
        sendPIDState();
        break;
      }
    case CMD_STORE_PID:
      {
        savePidToEEPROM();
        break;
      }
    case CMD_RESTORE_PID:
      {
        if (loadPidFromEEPROM()) {
          bool pidWasEnabled = (pidGlobal.flags & PID_FLAGS::PID_ENABLED) != 0;
          for (int i = 0; i < AXES_PER_BOARD; i++) {
            DMAStepper_SetPIDEnable(i, false);
            DMAStepper_SetPID(i, pidGlobal.Kp, pidGlobal.Ki, pidGlobal.Kd, pidGlobal.Ks);
            DMAStepper_SetPIDBlend(i, (float)pidGlobal.blend / 100.0f);
            if (pidWasEnabled) DMAStepper_SetPIDEnable(i, true);
          }
        }
        break;
      }
    default:
      {
        break;
      }
  }
}

void setup() {
  // 2026-08-23 CRITICAL FIX: Disable JTAG to free PB3, PB4, PA15 for GPIO use.
  // Keep only SWD (PA13/PA14) for debugging/flashing via ST-Link.
  // Without this, PB3 (JTDO) and PB4 (NJTRST) are locked by JTAG and
  // pinMode() calls silently fail — no STEP/DIR signals on Axis 2!
  afio_cfg_debug_ports(AFIO_DEBUG_SW_ONLY);

  // ВАЖНО: исключаем из цикла защищённые пины (PA13, PA14 — SWD)
  for (int pin = PA0; pin <= PC15; pin++) {
    if (pin == PA13 || pin == PA14) continue;  // Не трогаем SWD!
    pinMode(pin, INPUT_PULLDOWN);
  }
  pinMode(LED_PIN, OUTPUT);

  loadPidFromEEPROM();
  DMAStepper_Init();

  DMAStepper_InitAxis(0, AXIS0_STEP, AXIS0_DIR, AXIS0_LIMIT);
  DMAStepper_InitAxis(1, AXIS1_STEP, AXIS1_DIR, AXIS1_LIMIT);
  DMAStepper_InitAxis(2, AXIS2_STEP, AXIS2_DIR, AXIS2_LIMIT);

  for (int i = 0; i < AXES_PER_BOARD; i++) {
    DMAStepper_SetPID(i, pidGlobal.Kp, pidGlobal.Ki, pidGlobal.Kd, pidGlobal.Ks);
    DMAStepper_SetPIDBlend(i, (float)pidGlobal.blend / 100.0f);
    bool pidEnabled = (pidGlobal.flags & PID_FLAGS::PID_ENABLED) != 0;
    DMAStepper_SetPIDEnable(i, pidEnabled);
  }

  SPI_Controller_Init();

#if (CONTROLLER_MODE == CONTROLLER_MODE_MASTER)
  Serial.begin(SERIAL_BAUD_RATE);
  while (!Serial)
    ;
#else
  Serial.begin(SERIAL_BAUD_RATE);
#endif
  digitalWrite(LED_PIN, HIGH);
}

inline void serialEvent() {
#if (CONTROLLER_MODE == CONTROLLER_MODE_MASTER)
  int data_cnt = min(Serial.available(), RAW_DATA_LEN);
  if (data_cnt < 2) return;

  for (int t = 0; t < data_cnt; ++t) {
    int byte = Serial.read();
    if (rxOffset > 0) {
      rxBuffer[rxOffset++] = byte;
      if (rxOffset == RAW_DATA_LEN) {
        memcpy(&pccmd, rxBuffer, RAW_DATA_LEN);
        dataReceived = true;
        rxOffset = 0;
      }
    } else {
      if (byte == CMD_ID) {
        int nextByte = Serial.peek();
        if (nextByte == RAW_DATA_LEN) {
          rxBuffer[rxOffset++] = CMD_ID;
        }
      }
    }
  }
#endif
}

void loop() {
  serialEvent();
  if (dataReceived) {
    dataReceived = false;
    digitalWrite(LED_PIN, LOW);
    processCommand();
    digitalWrite(LED_PIN, HIGH);
  }
  DMAStepper_Process();

#if (CONTROLLER_MODE == CONTROLLER_MODE_SLAVE)
  SPI_Controller_Process();
#endif
}

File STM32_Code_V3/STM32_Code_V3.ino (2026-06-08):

// 3DOF by Andrey Zhuravlev
// Timer-based-stepping and PID controls added by Laith Wattar

// V3 Changes:
// - Motion Smoothing/Buffer removed
// - Toggleable PID motion shaping added:
//   - STM32 PID is NOT true closed-loop; it uses estimated step-count position (no encoder connection)
//   - Servo drives run their own PID loops internally with encoder feedback (true closed-loop)
//   - STM32 shapes step/dir commands before servo; servo corrects any position errors
//   - Ki MUST stay at 0 (servo speed loop already has integral - avoid double integration. Adjust it at your own risk.)
//   - V3 Code requires usage of an updated shmotioncontroller file. This will unlock custom SimHub PID sliders in the Protocol Control Panel (click on output settings).
//   - These sliders can change the PID parameters via I2C, but motion must first be disabled in SimHub. Once edited, re-enable motion and test.

// e-mail: v.azhure@gmail.com
// original version from 2025-06-21
// modified version from 2026-03-01
// modified version from 2026-03-10 : struct STATE speedMMperSEC uint8_t -> uint16_t. Overal length of struct not changed because of alignment
// modified version from 2026-03-19 : added enum PID_FLAGS, struct PID_STATE, updated command set enum COMMAND
// stm32duino version
// modified version from 2026-03-20 : Fixed Homing interruption logic (Reset/Disable now aborts homing state machine)
// modified version from 2026-03-28 : Fixed setStepFrequency, startStepping. Canceling homeing if CMD_CLEAR ALARM appear
// modified version from 2026-04-12 Master code: removed text commands for SimHub. (Sketch uses 31348 bytes (47%) of program storage space)
// Slave: Sketch uses 34500 bytes (52%) of program storage space.

//!!!!!!!!!!!!!!!!!!!!!!!!!!!! WARNING !!!!!!!!!!!!!!!!!!!!!!!!!!!!
// NOTE: MAKE SURE TO EDIT LINES FOR BALLSCREW LENGTH CONFIGURATION!
// Also please double check:
// -LED_PIN
// -MM_PER_REV - distance in mm per revolution
// -MAX_REVOLUTIONS - total travel distance devided by MM_PER_REV
// -STEPS_PER_REVOLUTIONS - Steps per revolution, decreased from 2000 to 1000 to accomadate slower STM32s (verify ratio on your specific servo controller)
//!!!!!!!!!!!!!!!!!!!!!!!!!!!! WARNING !!!!!!!!!!!!!!!!!!!!!!!!!!!!

// NOTE: select fake STM32F103C8 or Generik STM32F103C series, CPU Speed 74Mhz, upload method STLink, Optimize Fast (-O1)
// https://www.stm32duino.com/
//
// append to Board Manager URLs:
// http://dan.drown.org/stm32duino/package_STM32duino_index.json
// https://github.com/stm32duino/BoardManagerFiles/raw/main/package_stmicroelectronics_index.json
//
// Download and install ST-Link Utility https://www.st.com/en/development-tools/stsw-link004.html

// #define DEBUG
// Board: STM32F103C8T6 5 pcs (master + 4 slave)

#define I2C_SDA PB7
#define I2C_SCL PB6
#include <Wire_slave.h>
#include <stdio.h>
#include <bitset>
#include <math.h>
//#include <ctype.h>

// Uncomment this line if you using SF1610
#define SFU1610  // Used only in SLAVE devices

// Uncomment this line to flash MASTER device
// Comment this line to flash SLAVE devices
#define I2CMASTER

// Maximal number of linear actuators
#define MAX_LINEAR_ACTUATORS 4
// Number of linear actuators
#define LINEAR_ACTUATORS MAX_LINEAR_ACTUATORS

#define SLAVE_ADDR_FL 10  // Front / Front Left
#define SLAVE_ADDR_RL 11  // Rear Left
#define SLAVE_ADDR_RR 12  // Rear Right
#define SLAVE_ADDR_FR 13  // Front RIGHT

#define SLAVE_FIRST SLAVE_ADDR_FL
#define SLAVE_LAST (SLAVE_FIRST + LINEAR_ACTUATORS - 1)

void allPinsPulldown() {
  for (int pin = PA0; pin <= PC15; pin++) pinMode(pin, INPUT_PULLDOWN);
}

inline int WireRead(uint8_t* ptr, uint8_t len) {
  int cnt = Wire.available();
  len = len > cnt ? cnt : len;
  for (int t = 0; t < len; t++) {
    ptr[t] = Wire.read();
  }
  return len;
}

template<class T>
const T& clamp(const T& x, const T& a, const T& b) {
  if (x < a) {
    return a;
  } else if (b < x) {
    return b;
  } else
    return x;
}

#ifndef I2CMASTER
/////////////////////////////////////////////////////////////////////////////////////////////////////////////
// Uncomment a single line with desired Address to flash SLAVE device
#define SLAVE_ADDR SLAVE_ADDR_FL
//#define SLAVE_ADDR SLAVE_ADDR_RL
//#define SLAVE_ADDR SLAVE_ADDR_RR
//#define SLAVE_ADDR SLAVE_ADDR_FR
#endif

#define SERIAL_BAUD_RATE 115200

// override Serial Port buffer size
#define SERIAL_TX_BUFFER_SIZE 512
#define SERIAL_RX_BUFFER_SIZE 512

#define LED_PIN PC13 //PB2  // PC13  // * Check your board. Some have PB2 or another (label near LED).

enum MODE : uint8_t { UNKNOWN,
                      CONNECTED,
                      DISABLED,
                      HOMEING,
                      PARKING,
                      READY,
                      ALARM,
                      PARKED,
                      UNPARKING
};

enum COMMAND : uint8_t { CMD_HOME,
                         CMD_MOVE,
                         CMD_SET_SPEED,
                         CMD_DISABLE,
                         CMD_ENABLE,
                         CMD_GET_STATE,
                         CMD_CLEAR_ALARM,
                         CMD_PARK,
                         SET_ALARM,
                         CMD_SET_SLOW_SPEED,
                         CMD_SET_ACCEL,
                         CMD_MOVE_SH,
                         CMD_SET_PID_KP,      // 0x0C
                         CMD_SET_PID_KI,      // 0x0D
                         CMD_SET_PID_KD,      // 0x0E
                         CMD_SET_PID_KS,      // 0x0F
                         CMD_SET_PID_ENABLE,  // 0x10
                         CMD_SET_PID_BLEND,   // 0x11
                         CMD_GET_PID_STATE,   // 0x12
                         CMD_STORE_PID,       // 0x13
                         CMD_RESTORE_PID      // 0x14
};

enum FLAGS : uint8_t { NONE = 0,
                       STATE_ON_LIMIT_SWITCH = 1,
                       STATE_HOMED = 1 << 1,
};

enum PID_FLAGS : uint8_t {
  PID_NONE = 0,
  PID_ENABLED = 1,
  PID_MASTER_SYNC = 1 << 1,
  PID_DIAG_ENABLED = 1 << 2,  // Diagnostics: set false after validation if SimHub parsing is affected.
};

#define PID_STATE_ID 255

#define HAS_FLAG(x, flag) (((x) & (flag)) == (flag))
#define SET_FLAG(x, flag) ((x) = static_cast<decltype(x)>((x) | (flag)))
#define CLEAR_FLAG(x, flag) ((x) = static_cast<decltype(x)>((x) & ~(flag)))
#define TOGGLE_FLAG(x, flag) ((x) = static_cast<decltype(x)>((x) ^ (flag)))

struct STATE {
  MODE mode;
  FLAGS flags;
  uint16_t speedMMperSEC;
  int32_t currentpos;
  int32_t targetpos;
  int32_t min;
  int32_t max;
};

const int STATE_LEN = sizeof(STATE);

struct PCCMD {
  uint8_t header = 0;
  uint8_t len;  // len
  COMMAND cmd;
  uint8_t reserved;
  int32_t data[MAX_LINEAR_ACTUATORS];
} pccmd;

// FOR SimHub
struct PCCMD_SH {
  uint8_t header = 0;
  uint8_t len;  // len
  COMMAND cmd;
  uint8_t reserved;
  uint16_t data[MAX_LINEAR_ACTUATORS];
  uint16_t data2[MAX_LINEAR_ACTUATORS];  // EMPTY
};
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

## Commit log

2026-04-03 Add files via upload
    Single STM32F103 3dof controller (W.I.P)
2026-04-03 Add files via upload
    while (Serial.available()) loop fix, NC limits switch logic fix
    [STM32_F103_3DOF.ino, dma_stepper_hal.cpp]
2026-04-03 Add files via upload
    missed CMD_MOVE_SH added
    [STM32_F103_3DOF.ino]
2026-04-04 Add files via upload
    serial loop fix
    [STM32_F103_3DOF.ino]
2026-04-05 Add files via upload
    Limit switches debouncing added
2026-04-05 Add files via upload
    Reordered limit switch pins... it's better for PCB traces
2026-04-12 Add files via upload
    Master code: removed PID text commands for SimHub. (Sketch uses 31348 bytes (47%) of program storage space)
    Slave: Sketch uses 34500 bytes (52%) of program storage space.
2026-04-12 Add files via upload
    SimHub version for PID testing
2026-07-29 Шуточная страничка сравнения
    Шуточная страничка сравнения Moza HMA150 vs MozЯ Х90
2026-08-19 Add files via upload
    small fixes, SPI still not working ((((
    [STM32_F103_6DOF.ino, dma_stepper_hal.cpp, dma_stepper_hal.h]
2026-08-20 Add files via upload
    SPI fix. Still buggy
    [STM32_F103_6DOF.ino, dma_stepper_hal.cpp, dma_stepper_hal.h]
2026-08-20 Add files via upload
    SPI between MASTER and SLAVE finally works
2026-08-23 Add files via upload
    CRITICAL FIX: Disable JTAG to free PB3, PB4, PA15 for GPIO use.
    [STM32_F103_6DOF.ino, dma_stepper_hal.cpp, dma_stepper_hal.h]
